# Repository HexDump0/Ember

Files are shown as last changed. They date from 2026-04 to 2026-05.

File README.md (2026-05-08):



[][contributors-url]
[][forks-url]
[][stars-url]
[][issues-url]

<br />
<div align="center">
<h3 align="center">Ember</h3>

  <p align="center">
    A cheap, diy model rocket with a flight recorder and everything else you would need to fy it
    <br />
    <a href="https://github.com/HexDump0/Ember"><strong>See the guide »</strong></a>
    <br />
    <br />
    <a href="#">Video (Soon)</a>
    &middot;
    <a href="https://github.com/HexDump0/Ember/tree/master/models">Models</a>
    &middot;
    <a href="https://github.com/HexDump0/Ember/tree/master/gerber">Gerber</a>
    &middot;
    <a href="https://github.com/HexDump0/Ember/releases/tag/v1.0">Firmware</a>
  </p>
</div>

## About The Project

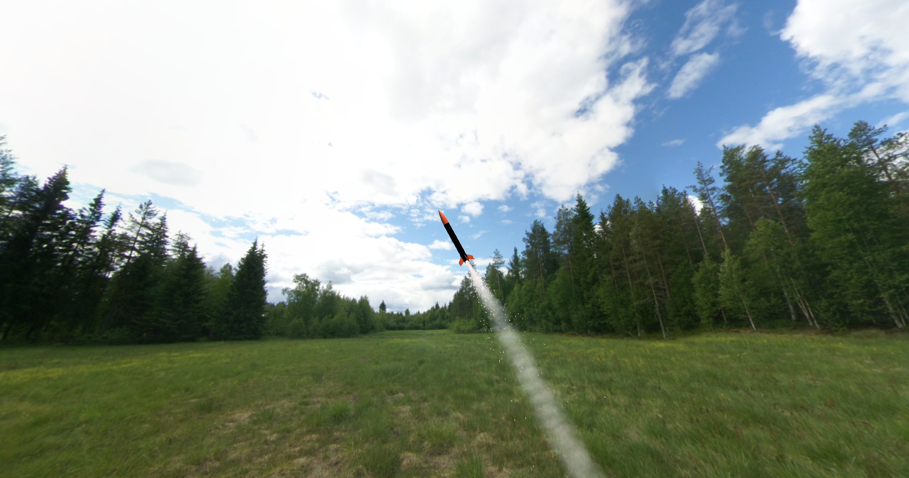
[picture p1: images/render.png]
Render


Ember is a diy, cheap and open source model rocket along with everything you would need to launch it + detailed guides on actually building it

<p align="right">(<a href="#readme-top">back to top</a>)</p>

## Images

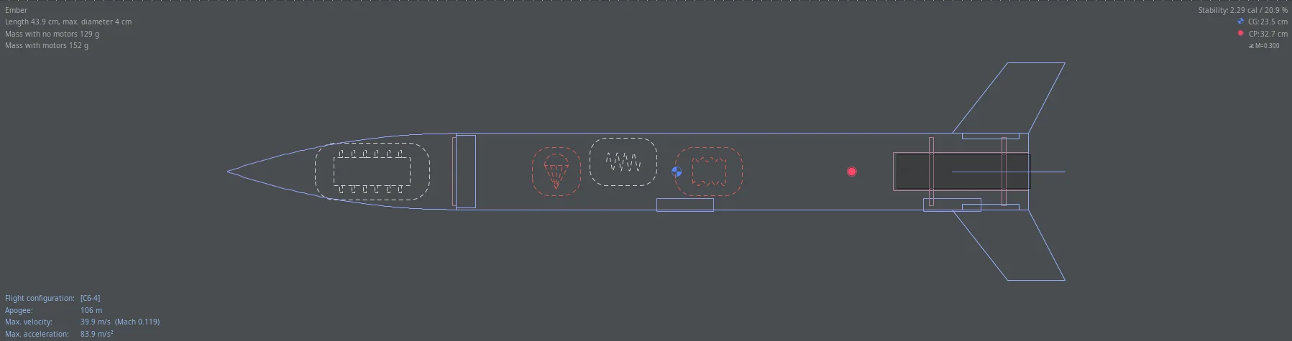
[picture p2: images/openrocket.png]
OpenRocket


|  | | |
|:---:|:---:|:---:|
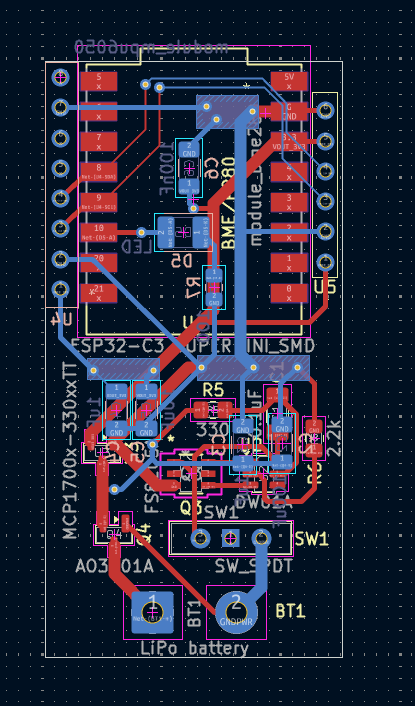
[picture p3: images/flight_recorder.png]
Flight Recorder
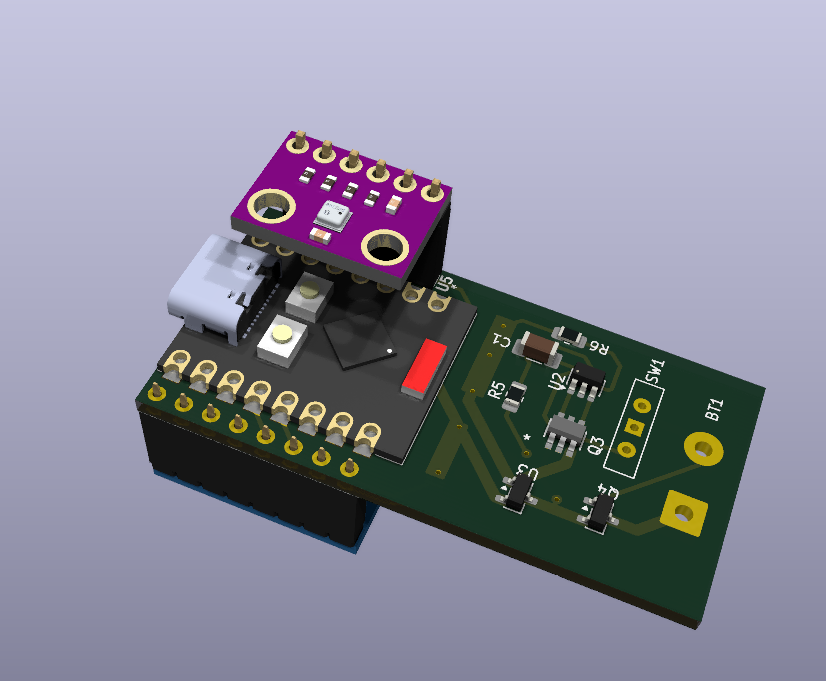
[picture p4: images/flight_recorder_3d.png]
Flight Recorder 3D
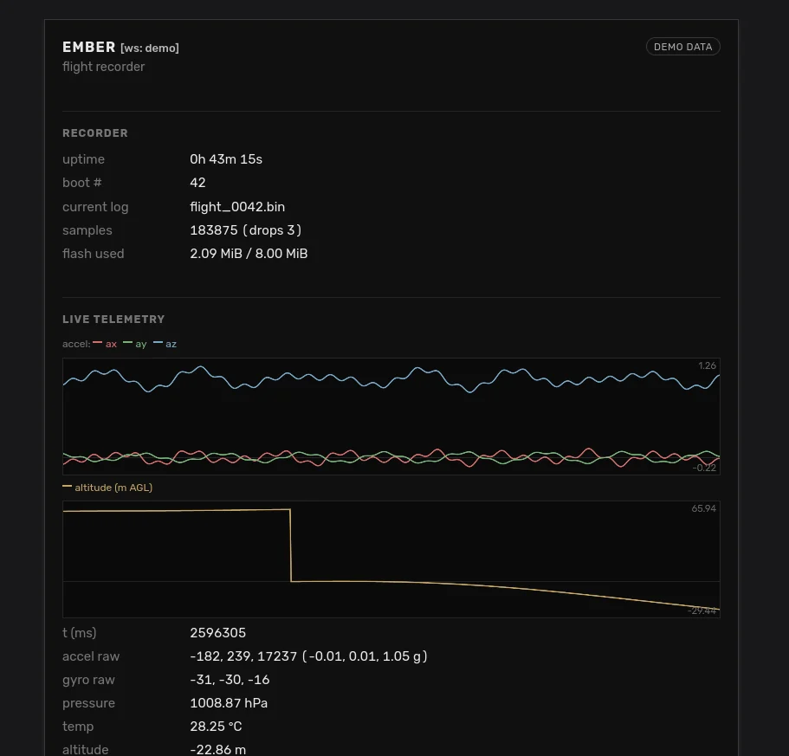
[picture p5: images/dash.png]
Dashboard
| <br><sub>Flight Recorder</sub> | <br><sub>Flight Recorder 3D</sub> | <br><sub>Dashboard</sub> |
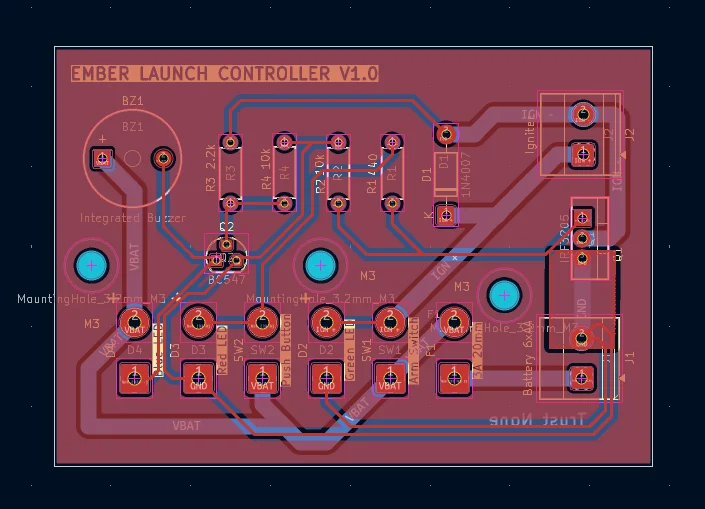
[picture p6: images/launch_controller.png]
Launch Controller
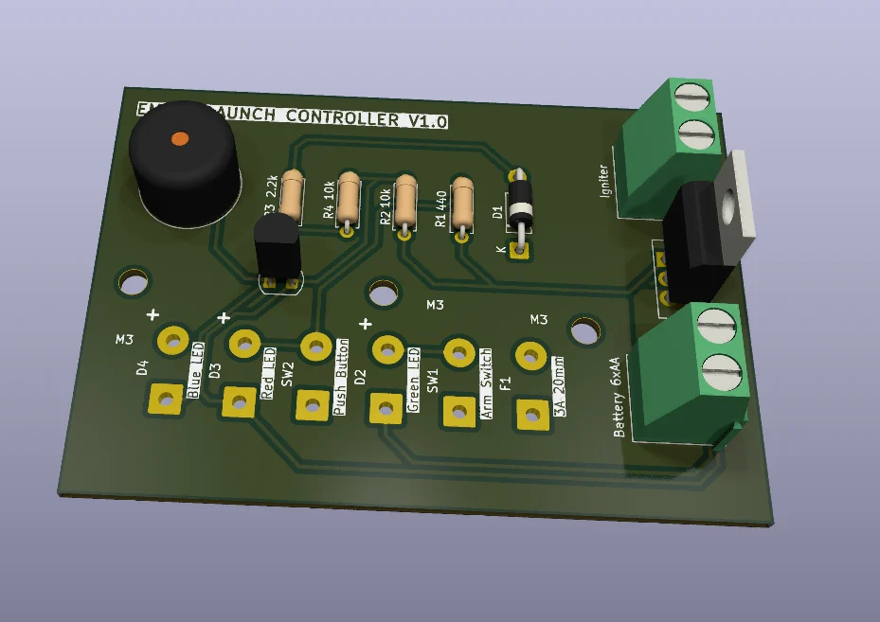
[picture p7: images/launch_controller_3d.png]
Launch Controller 3D
| <br><sub>Launch Controller</sub> | <br><sub>Launch Controller 3D</sub> |  |

## Guide

### 3D Printing
A few of the important parts of the rocket are 3d printed, you could get away with using PLA for them but ABS is better if you have it.

Recommended print settings:
- Layer heigh  -> 0.2mm
- Wall lines -> 5
- Infill -> Gyroid 40%
- Top & Bottom layers -> 4

### Nose cone
Add normal supports for the lip in the shoulder. It should come off easily

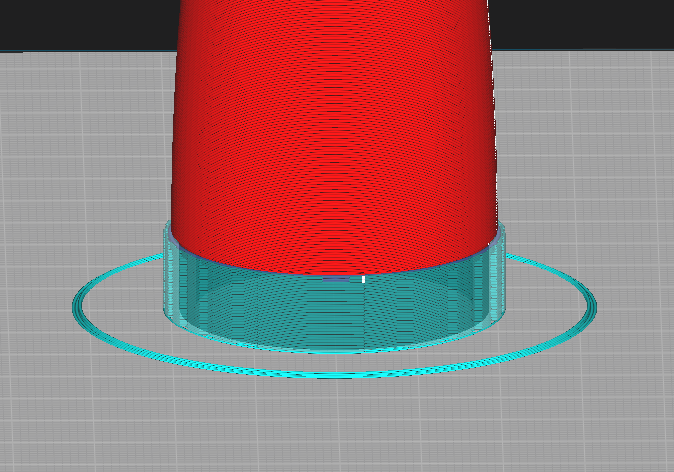
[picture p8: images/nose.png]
Nose


### Fins x4
Print it with the fin tab facing the bed and with the `Seam corner preference` set to `Hide Seam`

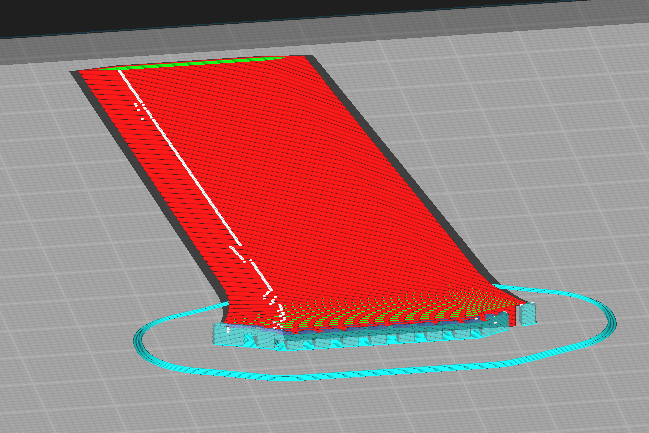
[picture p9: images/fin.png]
Fins


### Launch lugs x2
### Engine block
### Centering rings x2
### Launch Controller Body/Panel
### Launch Pad Leg/Body

You can just print these with the recommenced settings 

### PCB/Electronics

The gerber files for both the launch controller and flight recorder are available [here](https://github.com/HexDump0/Ember/tree/master/gerber)

Make sure you would a bit of 22 AWG wires at hand for the panel lights and switches

The Battery is meant to be charged on the bench and then soldered on to the flight recorder

(More detailed guide will come once I get my PCBs)

### Flashing the firmware

You need [`esptool`](https://docs.espressif.com/projects/esptool/). Install it using

```sh
pip install --user esptool
```

Plug the Super Mini into USB. It should show up as `/dev/ttyACM0` on Linux,
`/dev/tty.usbmodem*` on macOS, and `COMx` on Windows

Flash the [firmware](https://github.com/HexDump0/Ember/releases/tag/v1.0) using

```sh
esptool --chip esp32c3 --port /dev/ttyACM0 --baud 460800 \
        write-flash 0x0 ember.bin
```

Once done you should see some logs in serial

```sh
# pick one
idf.py -p /dev/ttyACM0 monitor
miniterm /dev/ttyACM0 115200
screen /dev/ttyACM0 115200
```
```
I (xxx) ember: ember boot
I (xxx) sensors: MPU6050 ready @0x68
I (xxx) sensors: BMP280 ready @0x76 ...
I (xxx) httpd: http server up on :80
I (xxx) wifi_ap: softap up: ssid=ember-XXXXXX ch=1
```

Connect to the open Wi-Fi `ember-XXXXXX` and visit
<http://192.168.4.1> for the dashboard.

## License

Distributed under the Creative Commons Attribution-NonCommercial 4.0. See `LICENSE.md` for more information.

<p align="right">(<a href="#readme-top">back to top</a>)</p>

## Contact

HexDump0 - [@HexDump0](https://x.com/hexdump0) - root@hexdump0.pw

Project Link: [https://github.com/HexDump0/Ember](https://github.com/HexDump0/Ember)

<p align="right">(<a href="#readme-top">back to top</a>)</p>

## Acknowledgments

* [SnapEDA](https://www.snapeda.com) for ESP32-C3 SMD Footprint and Symbol
* [UltraLibrarian](https://www.ultralibrarian.com) for FS8205A Footprint and Symbol
* [RabchikEngineer](https://github.com/RabchikEngineer) for KiCad ESP32-C3-SuperMini symbols
* [Ulf Hille](https://grabcad.com/library/esp32c3-supermini-1) for ESP32C3 SuperMini 3D Model
* [Usini](https://ko-fi.com/usini) for Usini Sensors Kicad Schematics and footprints (and associated GrabCAD authors)

<p align="right">(<a href="#readme-top">back to top</a>)</p>

[contributors-shield]: https://img.shields.io/github/contributors/HexDump0/Ember.svg?style=for-the-badge
[contributors-url]: https://github.com/HexDump0/Ember/graphs/contributors
[forks-shield]: https://img.shields.io/github/forks/HexDump0/Ember.svg?style=for-the-badge
[forks-url]: https://github.com/HexDump0/Ember/network/members
[stars-shield]: https://img.shields.io/github/stars/HexDump0/Ember.svg?style=for-the-badge
[stars-url]: https://github.com/HexDump0/Ember/stargazers
[issues-shield]: https://img.shields.io/github/issues/HexDump0/Ember.svg?style=for-the-badge
[issues-url]: https://github.com/HexDump0/Ember/issues
[license-shield]: https://img.shields.io/github/license/HexDump0/Ember.svg?style=for-the-badge
[license-url]: https://github.com/HexDump0/Ember/blob/master/LICENSE.md

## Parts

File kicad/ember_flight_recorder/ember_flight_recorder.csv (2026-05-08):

Reference | Qty | Name | Link | Additional | Alternative
BT1 | 1 | LiPo battery | https://makerbazar.in/products/3-7v-250mah-lipo-battery-single-cell-rechargeable?variant=49496666833136
C1 | 1 | 0.1uF | https://robu.in/product/0-1uf-capacitor-smdc-1206 |  | https://makerbazar.in/products/1206-smd-smt-mlcc-capacitor?variant=48370327126256
C2 | 1 | 100uF | https://robu.in/product/grm31cd80j107me39l-murata-electronics-6-3v-100uf-x6t-%c2%b120-1206-multilayer-ceramic-capacitors-mlcc-smd-smt-rohs
C3,C4 | 2 | 1uF | https://robu.in/product/yageo-1uf-50v-smd-multilayer-ceramic-capacitor-pack-of-20
C5 | 1 | 10uF | https://robu.in/product/yageo-10uf-50v-smd-multilayer-ceramic-capacitor-pack-of-20
C6 | 1 | 100nF | https://robu.in/product/tcc1206m3l104j500ft-cctc-smt-ceramic-capacitors-1206-m3l-104j100nf%c2%b15-0-rated-voltage50v-thickness1-25mm-tape
D5 | 1 | LED | https://robu.in/product/1210-surface-mount-led-red-50-pcs
Q3 | 1 | FS8205A | https://robu.in/product/1-month-warranty-398
Q4 | 1 | AO3401A | https://robu.in/product/ao3401a-umwyoutai-semiconductor-co-ltd-30v-4-2a-50m%cf%8910v-1-4w-400mv-1-piece-p-channel-sot-23-mosfets-rohs
R5 | 1 | 330 | https://robu.in/product/cr0805j330rp05z-ever-ohms-tech-125mw-thick-film-resistor-%c2%b1100ppm-%e2%84%83-%c2%b15-330%cf%89-0805-chip-resistor-surface-mount-rohs
R6 | 1 | 2.2k | https://robu.in/product/rc0805fr-072k2l-yageo-125mw-thick-film-resistors-150v-%c2%b1100ppm-%e2%84%83-%c2%b11-2-2k%cf%89-0805-chip-resistor-surface-mount-rohs
R7 | 1 | 100 | https://robu.in/product/ac0805fr-7w100rl-yageo-res-thick-film-0805-100-ohm-1-0-25w1-4w-%c2%b1100ppm-c-pad-smd-t-r-automotive-aec-q200
SW1 | 1 | SW_SPDT | https://robu.in/product/4mm-spdt-1p2t-slide-switch-pack-of-10
U2 | 1 | DW01A | https://robu.in/product/dw01-a-j-fumen-electronics-co-ltd-protection-ic-for-one-cell-lithium-ion-lithium-polymer-battery-pack-sot-23-6
U3 | 1 | MCP1700x-330xxTT | https://robu.in/product/mcp1700t-3302e-tt-microchip-technology-3-3v-250ma-fixed-output-ldo-linear-voltage-regulator-3-pin-sot-23
U4 | 1 | module_mpu6050 | https://robu.in/product/mpu-6050-gyro-sensor-2-accelerometer
U5 | 1 | module_bme280 | https://robu.in/product/bmp280-barometric-pressure-and-altitude-sensor-i2c-spi-module
U6 | 1 | ESP32-C3_SUPERMINI_SMD

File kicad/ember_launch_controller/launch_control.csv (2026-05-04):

Reference | Qty | Name | Link | Additional | Alternative
BZ1 | 1 | Integrated Buzzer | https://robu.in/product/tmb12a12-cldz-electromagnetic-active-integrated-buzzer-12v12x9-5mm |  | https://makerbazar.in/products/small-active-buzzer?variant=47492470341872
D1 | 1 | Blue | https://robu.in/product/blue-ac-dc12v-16mm-ad16-16e-led-power-pilot-signal-indicator-lamp
D2 | 1 | Green | https://robu.in/product/green-ac-dc12v-22mm-ad16-22ds-led-power-pilot-signal-light-indicator
D3 | 1 | 1N4007 | https://robu.in/product/1n4007g-t-diodes-incorporated-1a-1v1a-1kv-do-41-diodes-general-purpose-rohs |  | https://makerbazar.in/products/1n5819-schottky-diode-1a-40v-do-41
D4 | 1 | Red | https://robu.in/product/red-ac-dc12v-16mm-led-power-pilot-signal-light
F1 | 1 | 3A 20mm | https://robu.in/product/0235003-hxp-littelfuse-0235003-hxp-fuse-cartridge-fast-acting-3-a-250-v-5mm-x-20mm-0-2-x-0-79-235 | https://robu.in/product/black-10a-250v-520mm-fuse-holder
J1 | 1 | Battery 6xAA | https://www.amazon.in/Universal-Combo-Mount-Terminal-Connectors/dp/B0GM2DT1X2 |  | https://makerbazar.in/products/wire-to-board-screw-terminal-connectors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
J2 | 1 | Igniter | https://www.amazon.in/Universal-Combo-Mount-Terminal-Connectors/dp/B0GM2DT1X2 |  | https://makerbazar.in/products/wire-to-board-screw-terminal-connectors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
Q1 | 1 | BC547 | https://robu.in/product/bc547-npn-transistor-pack-of-20 |  | https://robu.in/product/bc547-npn-transistor-pack-of-20
Q2 | 1 | IRF3205 | https://robu.in/product/irf3205-mosfet-pack-of-3 |  | https://makerbazar.in/products/irf-series-n-channel-power-mosfet-transistors
R1,R4 | 2 | 10k
R2 | 1 | 2.2k
R3 | 1 | 440 | https://robu.in/product/30-different-valued-metal-film-resistor-assorted-kit-for-diy-electronic-projects-and-experiments
SW1 | 1 | Arm Switch | https://robu.in/product/ks-01-101c-key-switch-12mm-2-positionon-off |  | https://makerbazar.in/products/electronic-2pin-key-switch-on-off-metal-lock-switch?variant=48251026833648
SW2 | 1 | Push Button | https://robu.in/product/onpow-las0-q-ds-r-220vt01-22t04-22mm-ac-dc-220v-red-led-pilot-lamp-push-button-ip40sealing-cover-sign-frame-4 |  | https://robu.in/product/12mm-12v-ring-light-self-lock-non-momentary-metal-push-button-switch-red-light

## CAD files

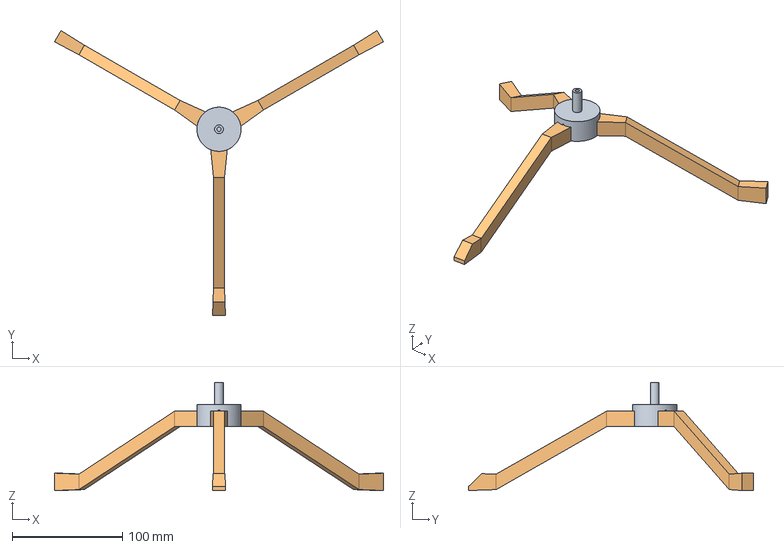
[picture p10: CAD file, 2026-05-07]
design/freecad/ember_launch_pad.FCStd
297.8 x 257.9 x 97.9 mm
Leg

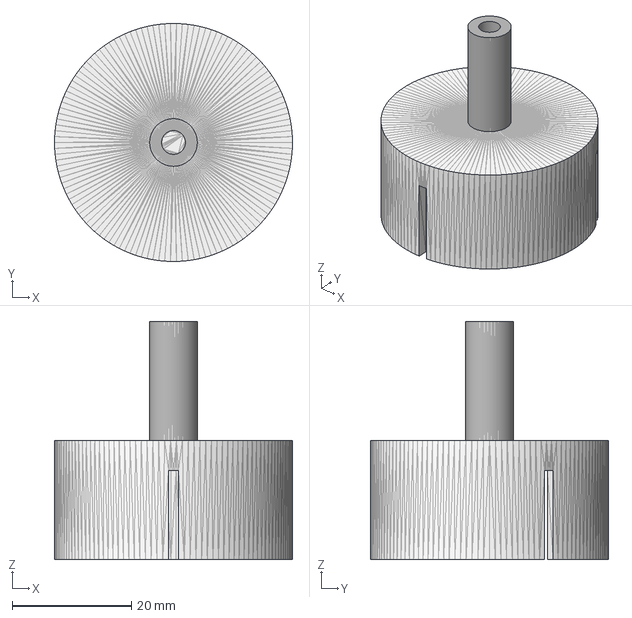
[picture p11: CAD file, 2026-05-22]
models/step/ember_launch_pad_body.step
40.0 x 40.0 x 40.0 mm

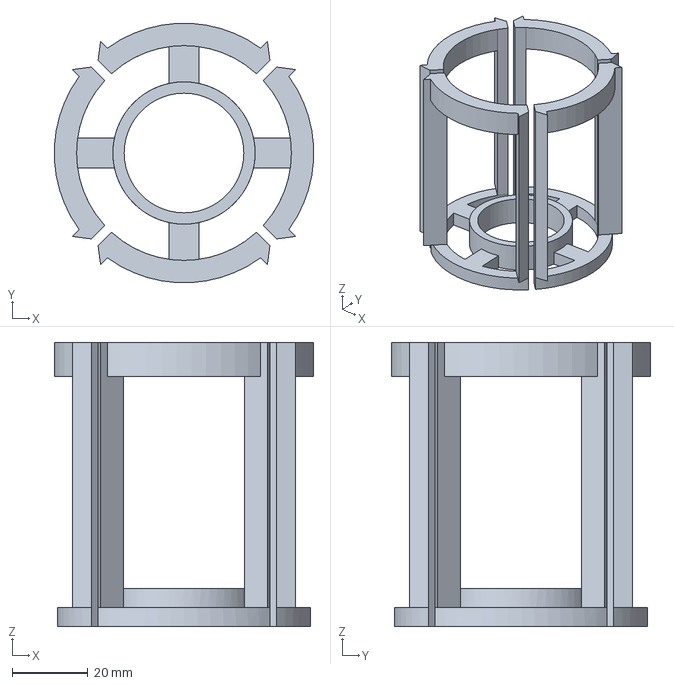
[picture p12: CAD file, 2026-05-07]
design/freecad/ember_fin_alignment.FCStd
68.4 x 68.4 x 75.0 mm

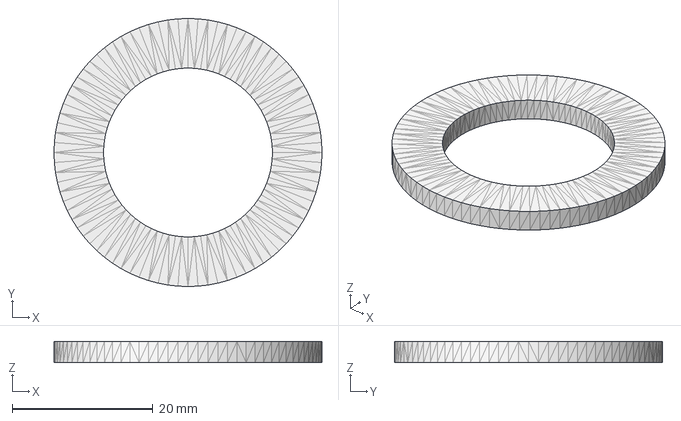
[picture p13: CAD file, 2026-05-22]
models/step/ember_centering_ring.step
38.1 x 38.1 x 3.00 mm

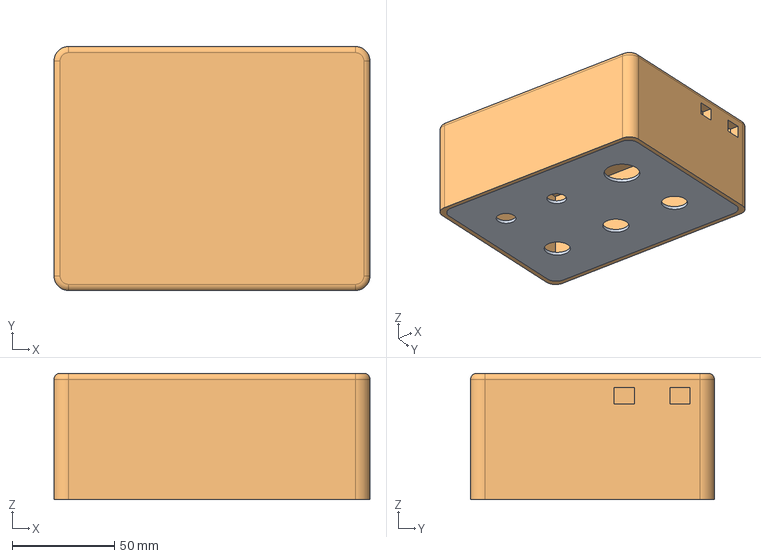
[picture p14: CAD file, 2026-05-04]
design/freecad/ember_launch_controller.FCStd
154.9 x 119.6 x 62.0 mm
Panel

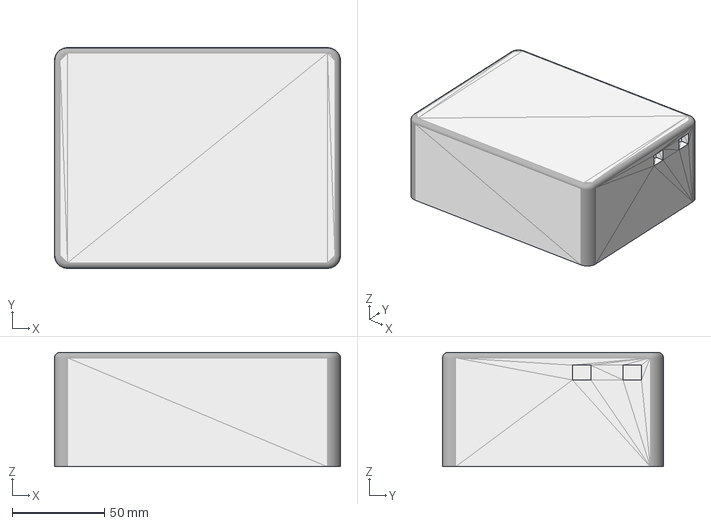
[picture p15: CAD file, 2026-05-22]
models/step/ember_launch_controller_body.step
154.9 x 119.6 x 62.0 mm

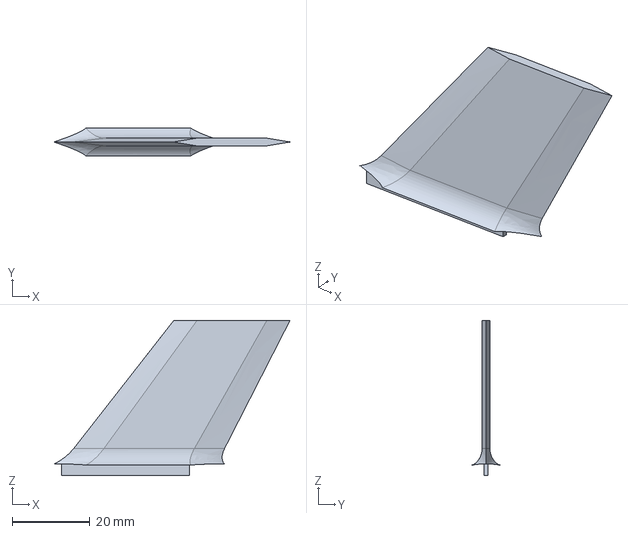
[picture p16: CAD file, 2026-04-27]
design/freecad/ember_fin.FCStd
60.9 x 7.15 x 40.0 mm

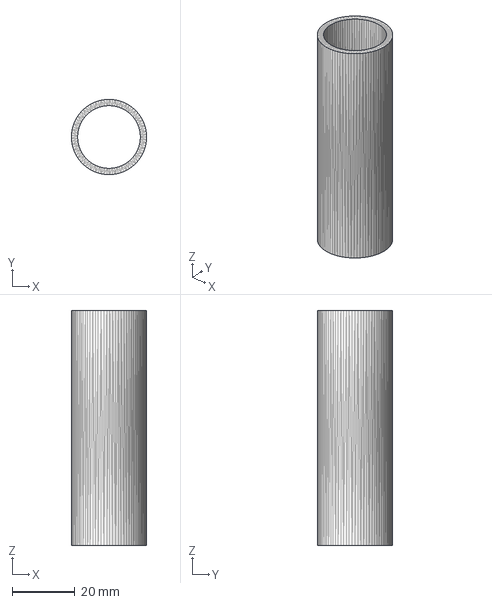
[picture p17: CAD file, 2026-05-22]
models/step/ember_engine_block.step
24.0 x 24.0 x 75.0 mm

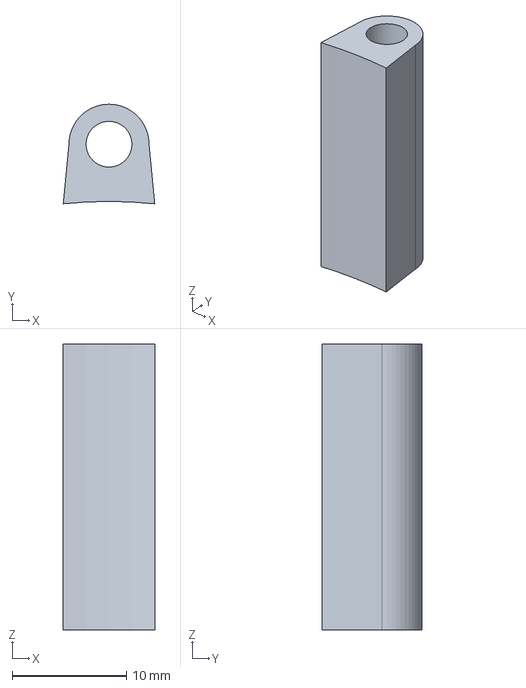
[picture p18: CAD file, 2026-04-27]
design/freecad/ember_lug.FCStd
8.00 x 8.71 x 25.0 mm

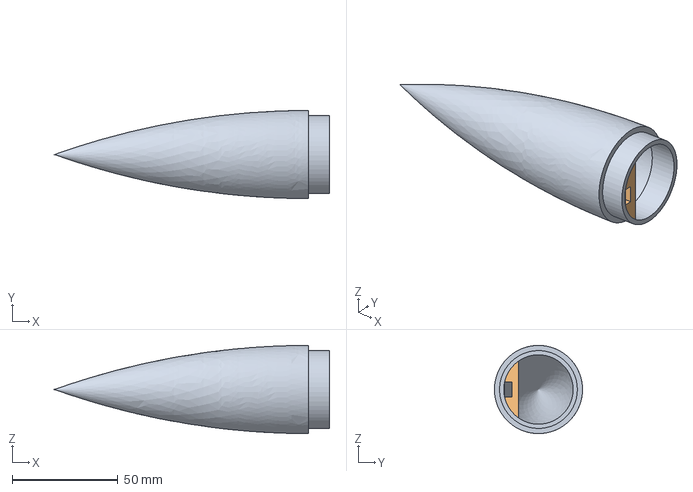
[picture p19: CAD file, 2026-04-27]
design/freecad/ember_nose.FCStd
130.0 x 41.7 x 41.7 mm
NoseCone001

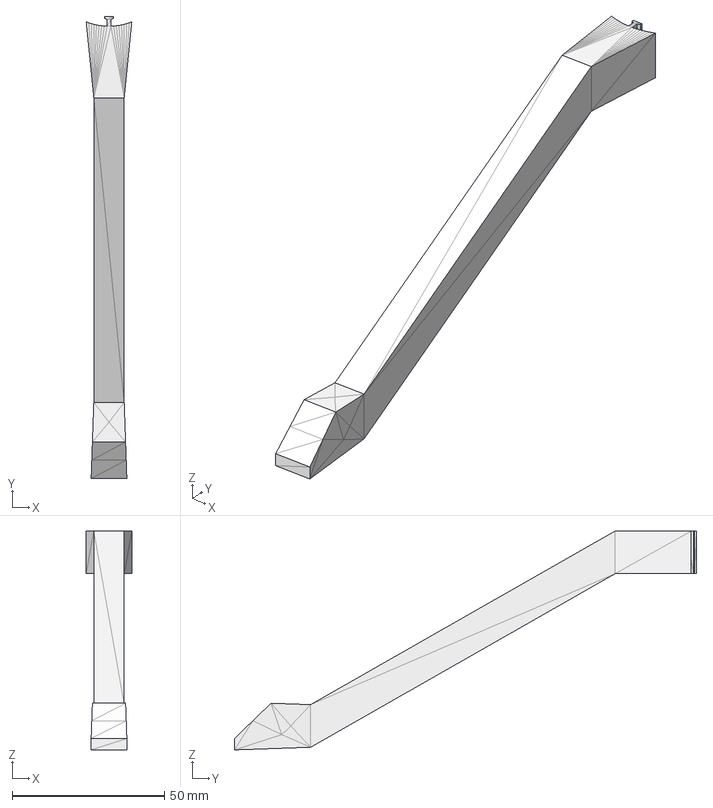
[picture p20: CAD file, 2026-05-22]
models/step/ember_launch_pad_leg.step
15.0 x 151.7 x 71.9 mm

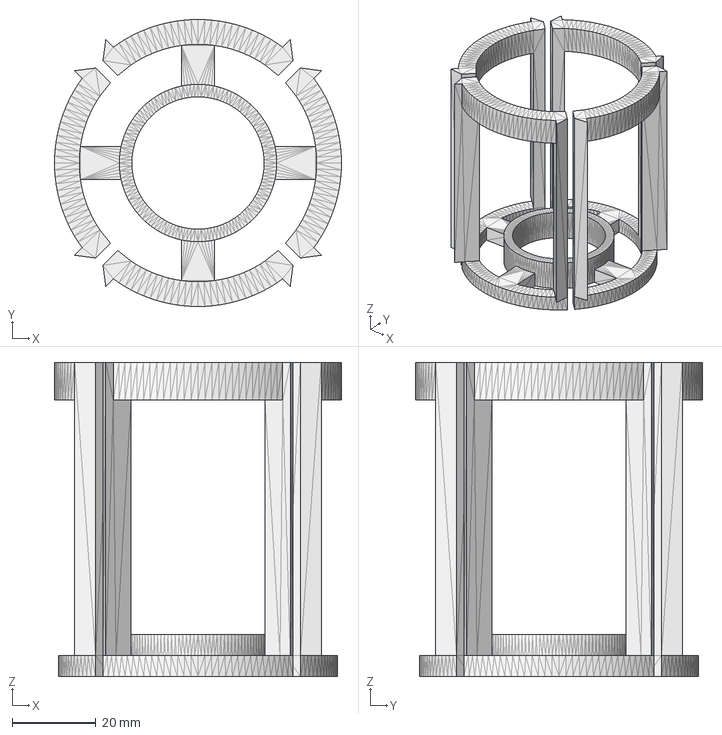
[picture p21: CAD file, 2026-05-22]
models/step/ember_fin_alignment.step
68.6 x 68.6 x 75.0 mm

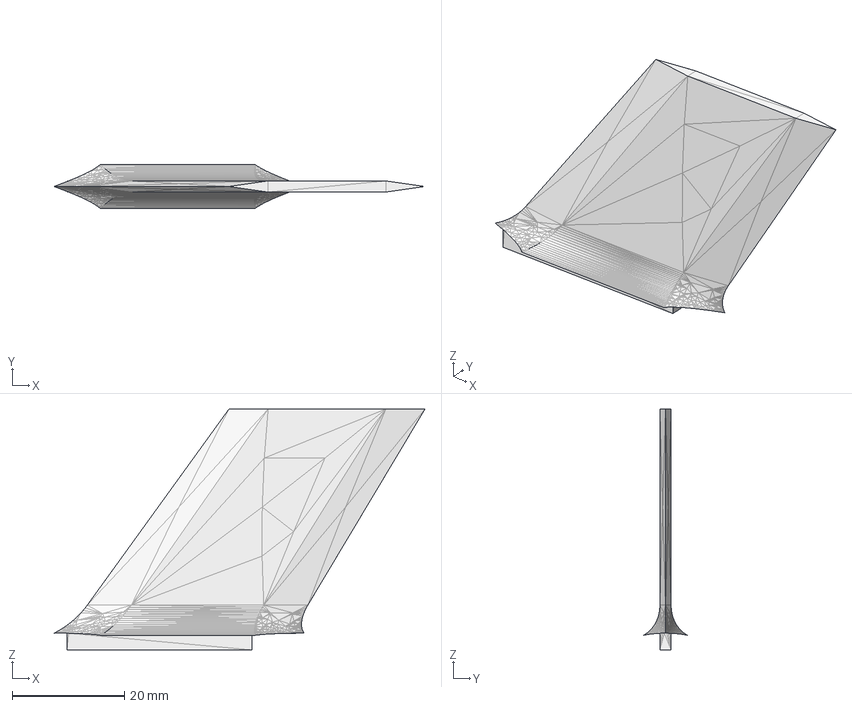
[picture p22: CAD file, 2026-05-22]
models/step/ember_fin.step
66.2 x 7.91 x 43.0 mm

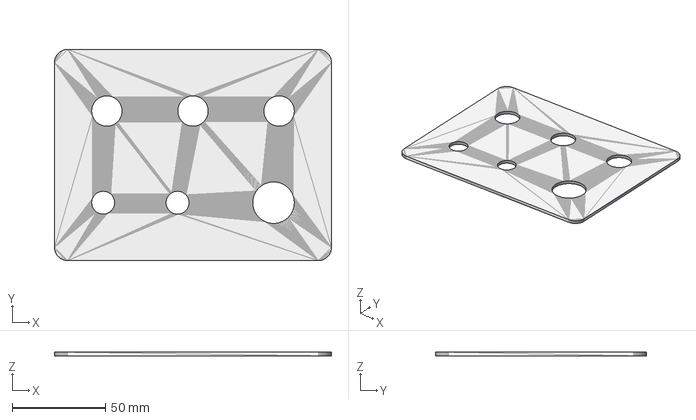
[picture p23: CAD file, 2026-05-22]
models/step/ember_launch_controller_panel.step
148.9 x 113.6 x 2.00 mm

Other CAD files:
models/step/ember_lug.step
models/step/ember_nose.step

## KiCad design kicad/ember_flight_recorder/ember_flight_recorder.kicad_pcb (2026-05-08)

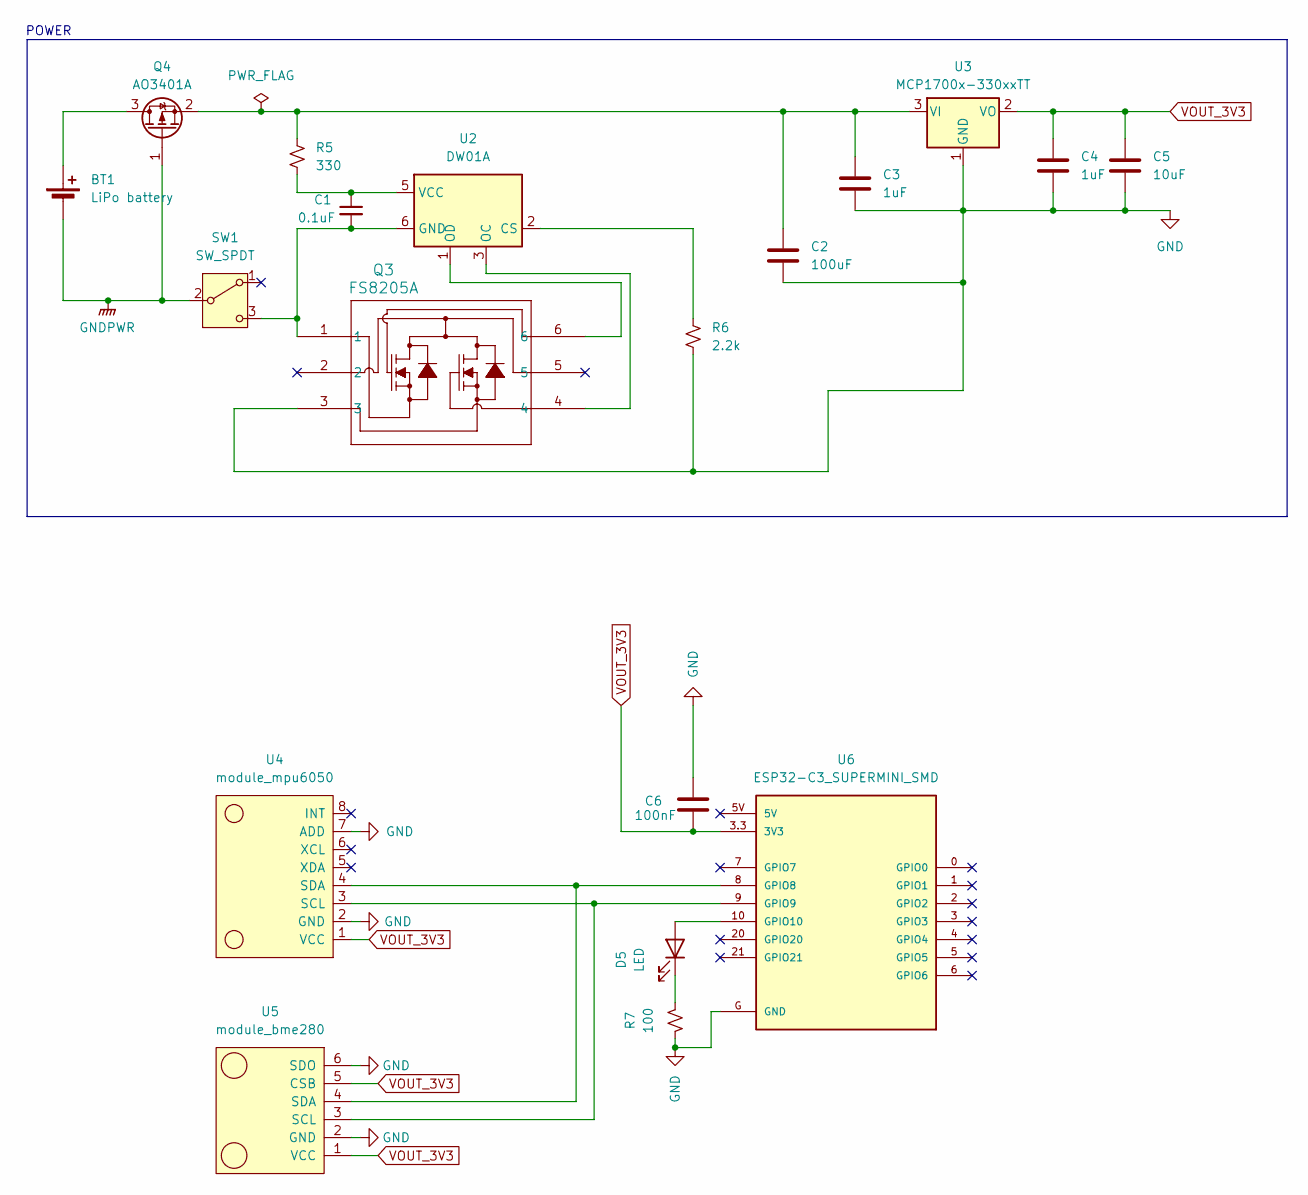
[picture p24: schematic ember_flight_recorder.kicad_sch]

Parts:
BT1: LiPo battery; SolderWire-0.75sqmm_1x02_P7mm_D1.25mm_OD3.5mm
C1: 0.1uF; C_1206_3216Metric_Pad1.33x1.80mm_HandSolder
C2: 100uF; C_1206_3216Metric_Pad1.33x1.80mm_HandSolder
C3, C4: 1uF; C_1206_3216Metric_Pad1.33x1.80mm_HandSolder
C5: 10uF; C_1206_3216Metric_Pad1.33x1.80mm_HandSolder
C6: 100nF; C_1206_3216Metric_Pad1.33x1.80mm_HandSolder
D5: LED; LED_1210_3225Metric_Pad1.42x2.65mm_HandSolder
Q3: FS8205A; SOT-23-6L_TCP-M
Q4: AO3401A; SOT-23
R5: 330; R_0805_2012Metric_Pad1.20x1.40mm_HandSolder
R6: 2.2k; R_0805_2012Metric_Pad1.20x1.40mm_HandSolder
R7: 100; R_0805_2012Metric_Pad1.20x1.40mm_HandSolder
SW1: SW_SPDT; SW_Slide-03_Wuerth-WS-SLTV_10x2.5x6.4_P2.54mm
U2: DW01A; SOT-23-6
U3: MCP1700x-330xxTT; SOT-23
U4: module_mpu6050
U5: module_bme280
U6: ESP32-C3_SUPERMINI_SMD; MODULE_ESP32-C3_SUPERMINI

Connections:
GND: C2.2, C3.2, C4.2, C5.2, C6.2, Q3.3, R6.2, R7.2, U3.1 (GND), U4.2 (GND), U4.7 (ADD), U5.2 (GND), U5.6 (SDO), U6.G (GND)
GNDPWR: BT1.2 (-), Q4.1 (G), SW1.2 (B)
unnamed: BT1.1 (+), Q4.3 (D)
unnamed: D5.2 (A), U6.10 (GPIO10)
unnamed: D5.1 (K), R7.1
unnamed: C2.1, C3.1, Q4.2 (S), R5.1, U3.3 (VI)
unnamed: C1.2, Q3.1, SW1.3 (C), U2.6 (GND)
unnamed: R6.1, U2.2 (CS)
unnamed: Q3.4, U2.3 (OC)
unnamed: Q3.6, U2.1 (OD)
unnamed: C1.1, R5.2, U2.5 (VCC)
unnamed: U4.3 (SCL), U5.3 (SCL), U6.9 (GPIO9)
unnamed: U4.4 (SDA), U5.4 (SDA), U6.8 (GPIO8)
VOUT_3V3: C4.1, C5.1, C6.1, U3.2 (VO), U4.1 (VCC), U5.1 (VCC), U5.5 (CSB), U6.3.3 (3V3)

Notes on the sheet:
POWER

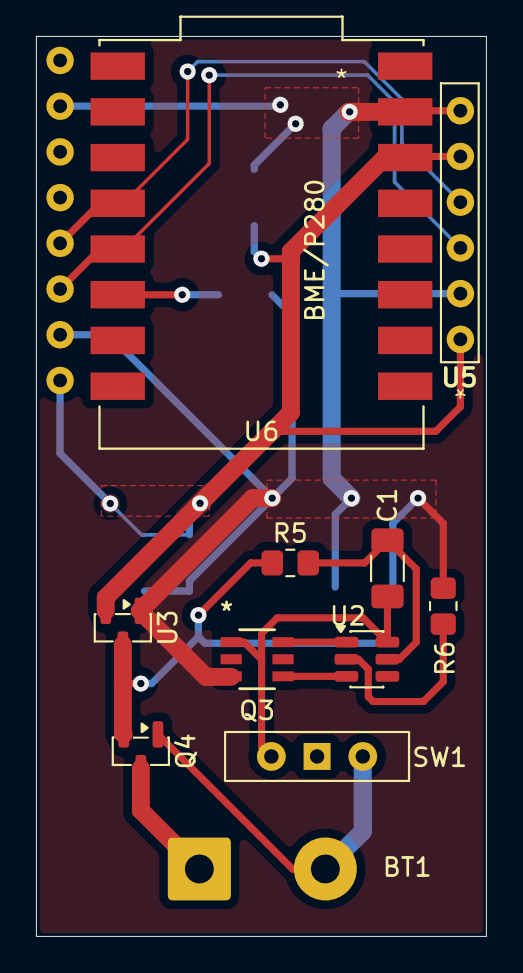
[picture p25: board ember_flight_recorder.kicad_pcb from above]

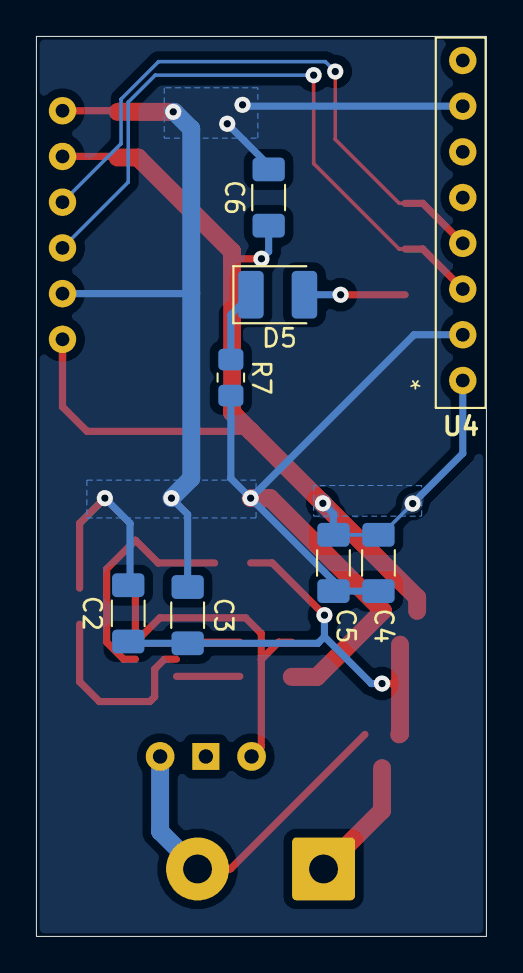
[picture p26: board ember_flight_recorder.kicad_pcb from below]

Board: 2 copper layers, 25.0 x 50.0 mm, 19 parts (8 on the bottom side), 14 nets.

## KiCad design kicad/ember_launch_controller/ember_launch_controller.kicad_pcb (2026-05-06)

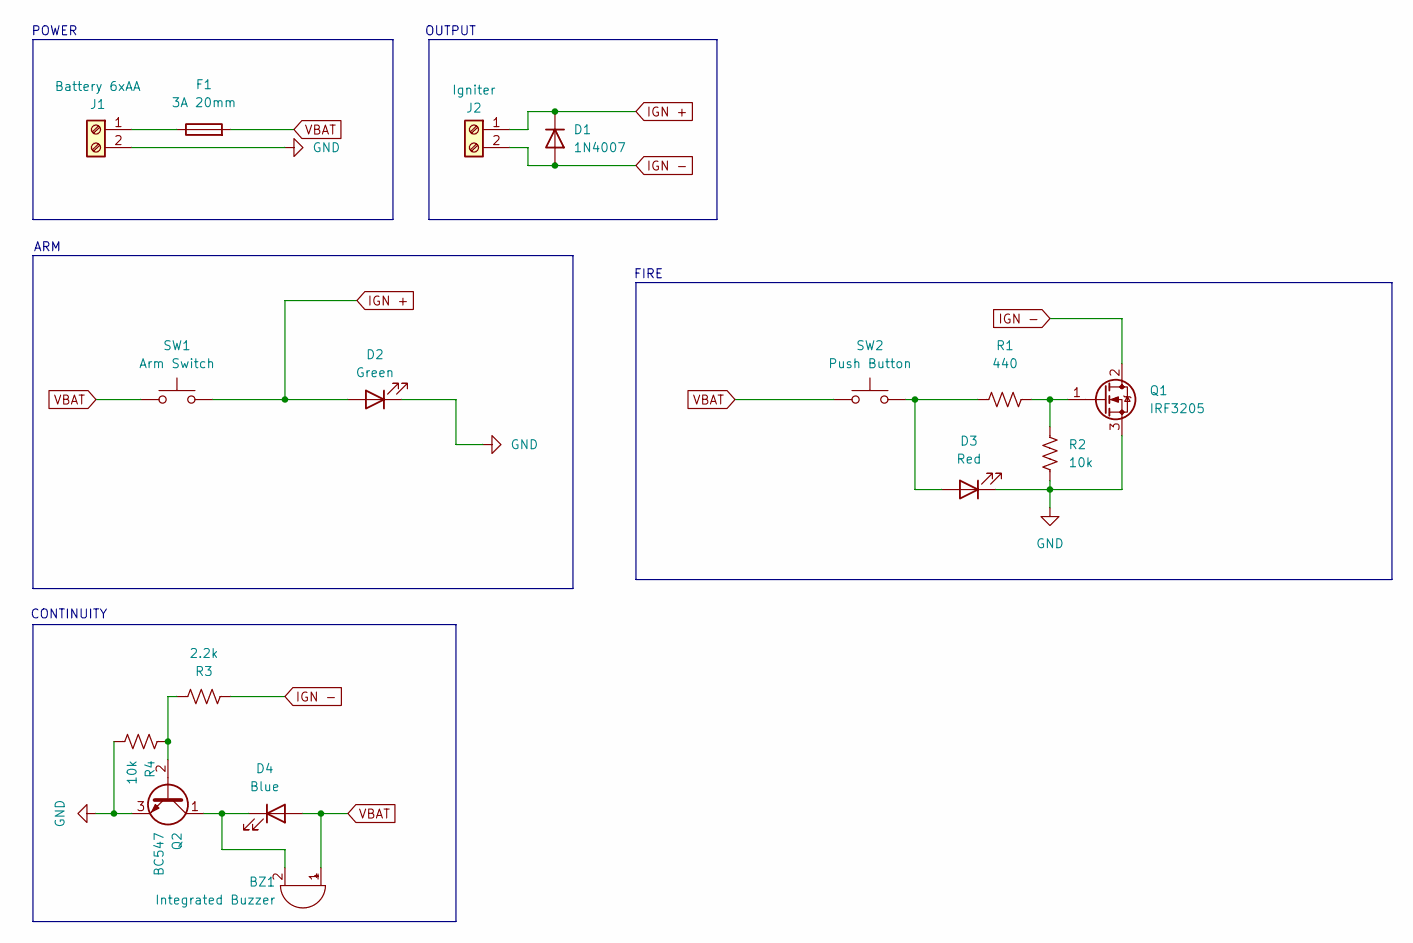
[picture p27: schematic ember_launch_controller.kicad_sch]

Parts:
BZ1: Integrated Buzzer; Buzzer_12x9.5RM7.6
D1: 1N4007; D_DO-41_SOD81_P10.16mm_Horizontal
D2: Green; SolderWire-0.75sqmm_1x02_P7mm_D1.25mm_OD3.5mm
D3: Red; SolderWire-0.75sqmm_1x02_P7mm_D1.25mm_OD3.5mm
D4: Blue; SolderWire-0.75sqmm_1x02_P7mm_D1.25mm_OD3.5mm
F1: 3A 20mm; SolderWire-0.75sqmm_1x02_P7mm_D1.25mm_OD3.5mm
J1: Battery 6xAA; TerminalBlock_Phoenix_MKDS-1,5-2_1x02_P5.00mm_Horizontal
J2: Igniter; TerminalBlock_Phoenix_MKDS-1,5-2_1x02_P5.00mm_Horizontal
Q1: IRF3205; TO-220-3_Vertical
Q2: BC547; TO-92_Inline
R1: 440; R_Axial_DIN0207_L6.3mm_D2.5mm_P7.62mm_Horizontal
R2, R4: 10k; R_Axial_DIN0207_L6.3mm_D2.5mm_P7.62mm_Horizontal
R3: 2.2k; R_Axial_DIN0207_L6.3mm_D2.5mm_P7.62mm_Horizontal
SW1: Arm Switch; SolderWire-0.75sqmm_1x02_P7mm_D1.25mm_OD3.5mm
SW2: Push Button; SolderWire-0.75sqmm_1x02_P7mm_D1.25mm_OD3.5mm

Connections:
GND: D2.1 (K), D3.1 (K), J1.2, Q1.3 (S), Q2.3 (E), R2.1, R4.1
IGN +: D1.1 (K), D2.2 (A), J2.1, SW1.2
IGN -: D1.2 (A), J2.2, Q1.2 (D), R3.2
unnamed: BZ1.2 (-), D4.1 (K), Q2.1 (C)
unnamed: D3.2 (A), R1.1, SW2.2
unnamed: F1.1, J1.1
unnamed: Q1.1 (G), R1.2, R2.2
unnamed: Q2.2 (B), R3.1, R4.2
VBAT: BZ1.1 (+), D4.2 (A), F1.2, SW1.1, SW2.1

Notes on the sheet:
OUTPUT
CONTINUITY
POWER
FIRE
ARM

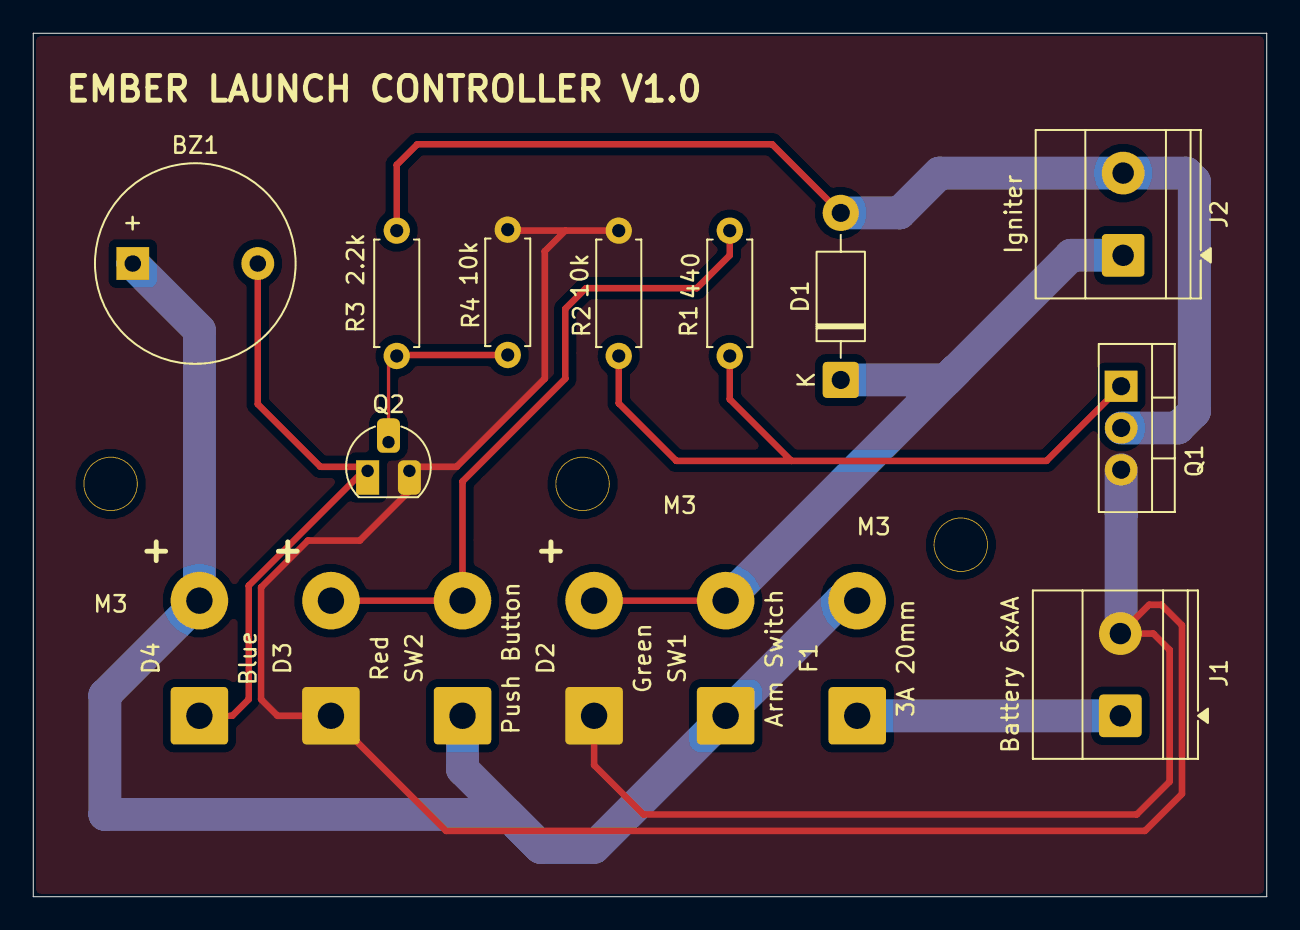
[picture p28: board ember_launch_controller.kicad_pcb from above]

Board: 2 copper layers, 75.0 x 52.5 mm, 19 parts (0 on the bottom side), 9 nets.

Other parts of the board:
M3, M3#2, M3#3: MountingHole_3.2mm_M3

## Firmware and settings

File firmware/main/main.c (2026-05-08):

#include "esp_log.h"
#include "freertos/FreeRTOS.h"
#include "freertos/queue.h"
#include "sdkconfig.h"

#include "http_server.h"
#include "logger.h"
#include "sensors.h"
#include "wifi_ap.h"

static const char *TAG = "ember";

void app_main(void)
{
    ESP_LOGI(TAG, "ember boot");

    ESP_ERROR_CHECK(sensors_init());

    QueueHandle_t log_queue = NULL;
    ESP_ERROR_CHECK(logger_start(&log_queue));
    ESP_ERROR_CHECK(sensors_start(log_queue));

#if !CONFIG_EMBER_FAKE_SENSORS
    ESP_ERROR_CHECK(wifi_ap_start());
    ESP_ERROR_CHECK(http_server_start());
#else
    ESP_LOGW(TAG, "wifi/httpd skipped (synthetic sensors)");
#endif
}

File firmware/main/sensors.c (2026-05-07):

#include "sensors.h"

#include <string.h>

#include "bmp280.h"
#include "driver/gpio.h"
#include "esp_log.h"
#include "esp_timer.h"
#include "freertos/FreeRTOS.h"
#include "freertos/semphr.h"
#include "freertos/task.h"
#include "i2cdev.h"
#include "mpu6050.h"

#define I2C_PORT          I2C_NUM_0
#define SDA_GPIO          GPIO_NUM_8
#define SCL_GPIO          GPIO_NUM_9

#define SAMPLE_PERIOD_MS  10           /* 100 Hz */
#define TASK_STACK        4096
#define TASK_PRIO         6

static const char *TAG = "sensors";

static mpu6050_dev_t s_mpu;
static bmp280_t      s_bmp;

static SemaphoreHandle_t s_latest_lock;
static ember_sample_t    s_latest;
static bool              s_have_latest;

static QueueHandle_t s_log_queue;

esp_err_t sensors_init(void)
{
    ESP_ERROR_CHECK(i2cdev_init());

    memset(&s_mpu, 0, sizeof(s_mpu));
    ESP_ERROR_CHECK(mpu6050_init_desc(&s_mpu, MPU6050_I2C_ADDRESS_LOW,
                                      I2C_PORT, SDA_GPIO, SCL_GPIO));
    ESP_ERROR_CHECK(mpu6050_init(&s_mpu));
    ESP_LOGI(TAG, "MPU6050 ready @0x%02x", MPU6050_I2C_ADDRESS_LOW);

    bmp280_params_t params;
    ESP_ERROR_CHECK(bmp280_init_default_params(&params));

    memset(&s_bmp, 0, sizeof(s_bmp));
    ESP_ERROR_CHECK(bmp280_init_desc(&s_bmp, BMP280_I2C_ADDRESS_0,
                                     I2C_PORT, SDA_GPIO, SCL_GPIO));
    ESP_ERROR_CHECK(bmp280_init(&s_bmp, &params));
    ESP_LOGI(TAG, "BMP280 ready @0x%02x (chip 0x%02x)",
             BMP280_I2C_ADDRESS_0, s_bmp.id);

    s_latest_lock = xSemaphoreCreateMutex();
    if (s_latest_lock == NULL) {
        return ESP_ERR_NO_MEM;
    }

    return ESP_OK;
}

esp_err_t sensors_read(ember_sample_t *out)
{
    mpu6050_raw_acceleration_t accel;
    mpu6050_raw_rotation_t     gyro;

    esp_err_t err = mpu6050_get_raw_acceleration(&s_mpu, &accel);
    if (err != ESP_OK) {
        return err;
    }
    err = mpu6050_get_raw_rotation(&s_mpu, &gyro);
    if (err != ESP_OK) {
        return err;
    }

    int32_t  temp_c100;
    uint32_t pressure_q24_8;
    err = bmp280_read_fixed(&s_bmp, &temp_c100, &pressure_q24_8, NULL);
    if (err != ESP_OK) {
        return err;
    }

    out->t_ms        = (uint32_t)(esp_timer_get_time() / 1000);
    out->ax          = accel.x;
    out->ay          = accel.y;
    out->az          = accel.z;
    out->gx          = gyro.x;
    out->gy          = gyro.y;
    out->gz          = gyro.z;
    out->pressure_pa = (int32_t)(pressure_q24_8 >> 8);
    out->temp_c100   = (int16_t)temp_c100;

    return ESP_OK;
}

bool sensors_get_latest(ember_sample_t *out)
{
    if (s_latest_lock == NULL) {
        return false;
    }
    xSemaphoreTake(s_latest_lock, portMAX_DELAY);
    bool have = s_have_latest;
    if (have) {
        *out = s_latest;
    }
    xSemaphoreGive(s_latest_lock);
    return have;
}

static void sensors_task(void *arg)
{
    (void)arg;

    TickType_t next = xTaskGetTickCount();
    uint32_t   read_errs = 0;
    uint32_t   q_drops   = 0;
    uint32_t   last_warn_ms = 0;

    for (;;) {
        ember_sample_t s;
        esp_err_t err = sensors_read(&s);
        if (err == ESP_OK) {
            xSemaphoreTake(s_latest_lock, portMAX_DELAY);
            s_latest      = s;
            s_have_latest = true;
            xSemaphoreGive(s_latest_lock);

            if (s_log_queue != NULL) {
                if (xQueueSend(s_log_queue, &s, 0) != pdTRUE) {
                    q_drops++;
                }
            }
        } else {
            read_errs++;
        }

        uint32_t now_ms = (uint32_t)(esp_timer_get_time() / 1000);
        if (now_ms - last_warn_ms >= 5000 && (read_errs || q_drops)) {
            ESP_LOGW(TAG, "in last %lu ms: %lu read errs, %lu queue drops",
                     (unsigned long)(now_ms - last_warn_ms),
                     (unsigned long)read_errs,
                     (unsigned long)q_drops);
            read_errs = 0;
            q_drops   = 0;
            last_warn_ms = now_ms;
        } else if (last_warn_ms == 0) {
            last_warn_ms = now_ms;
        }

        vTaskDelayUntil(&next, pdMS_TO_TICKS(SAMPLE_PERIOD_MS));
    }
}

esp_err_t sensors_start(QueueHandle_t log_queue)
{
    s_log_queue = log_queue;

    BaseType_t ok = xTaskCreate(sensors_task, "sensors",
                                TASK_STACK, NULL, TASK_PRIO, NULL);
    return (ok == pdPASS) ? ESP_OK : ESP_ERR_NO_MEM;
}

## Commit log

2026-05-01 added schematic and pcbs
    [ember.kicad_pcb, ember.kicad_sch, launch_control.kicad_sch]
2026-05-04 added launch controller models
    [ember.kicad_pcb, ember_launch_controller.FCStd, ember_launch_controller_body.obj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]
2026-05-04 updated to kicad 10
    [ember.kicad_pcb, ember.kicad_sch, launch_control.kicad_sch]
2026-05-05 added power management for battery
    [ember.kicad_sch, flight_recorder.kicad_sch]
2026-05-05 added sensors
    [flight_recorder.kicad_sch]
2026-05-05 restructured kicad project
    [ember.kicad_sch, ember_flight_recorder.kicad_pcb, ember_flight_recorder.kicad_sch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]
2026-05-05 updated footprint and 3d models
    [ember_flight_recorder.kicad_pcb, ember_flight_recorder.kicad_sch]
2026-05-05 flight recorder rev1
    [ember_flight_recorder.kicad_pcb, ember_flight_recorder.kicad_sch]
2026-05-06 flight recorder rev2
    [ember_flight_recorder.kicad_pcb]
2026-05-06 gerber files
    [ember_flight_recorder-B_Cu.gbr, ember_flight_recorder-B_Mask.gbr, ember_flight_recorder-B_Paste.gbr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]
2026-05-06 more gerber files
    [ember_launch_controller-B_Cu.gbr, ember_launch_controller-B_Mask.gbr, ember_launch_controller-B_Paste.gbr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]
2026-05-07 added fln alignment
    [ember_fin_alignment.FCStd, ember_fin_alignment.obj]
2026-05-07 added launch pad
    [ember_launch_pad.FCStd, ember_launch_pad_body.obj, ember_launch_pad_leg.obj]
2026-05-07 firmware init
    [partitions.csv]
2026-05-07 basic sensor data
2026-05-07 fake sensor for testing
2026-05-08 added file logging and http server
    [ember_flight_recorder-B_Cu.gbr, ember_flight_recorder-B_Mask.gbr, ember_flight_recorder-B_Paste.gbr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]
2026-05-22 added .step files
    [ember_centering_ring.step, ember_engine_block.step, ember_fin.step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]
